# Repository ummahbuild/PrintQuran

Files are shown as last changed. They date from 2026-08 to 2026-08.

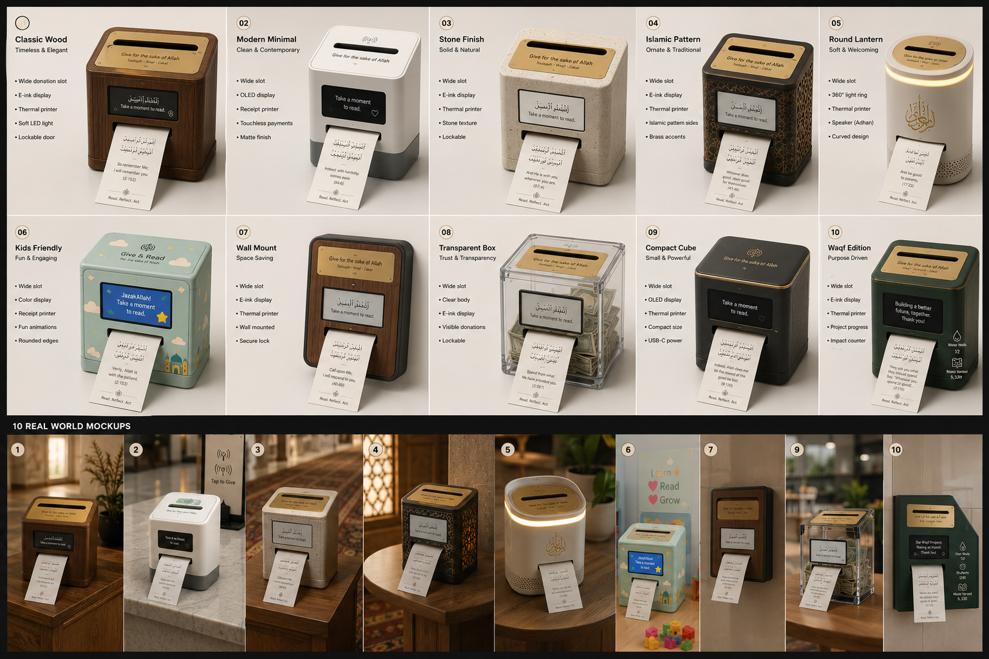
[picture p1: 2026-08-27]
reference-mockups/a_clean_product_design_board_concept_sheet_moc.png

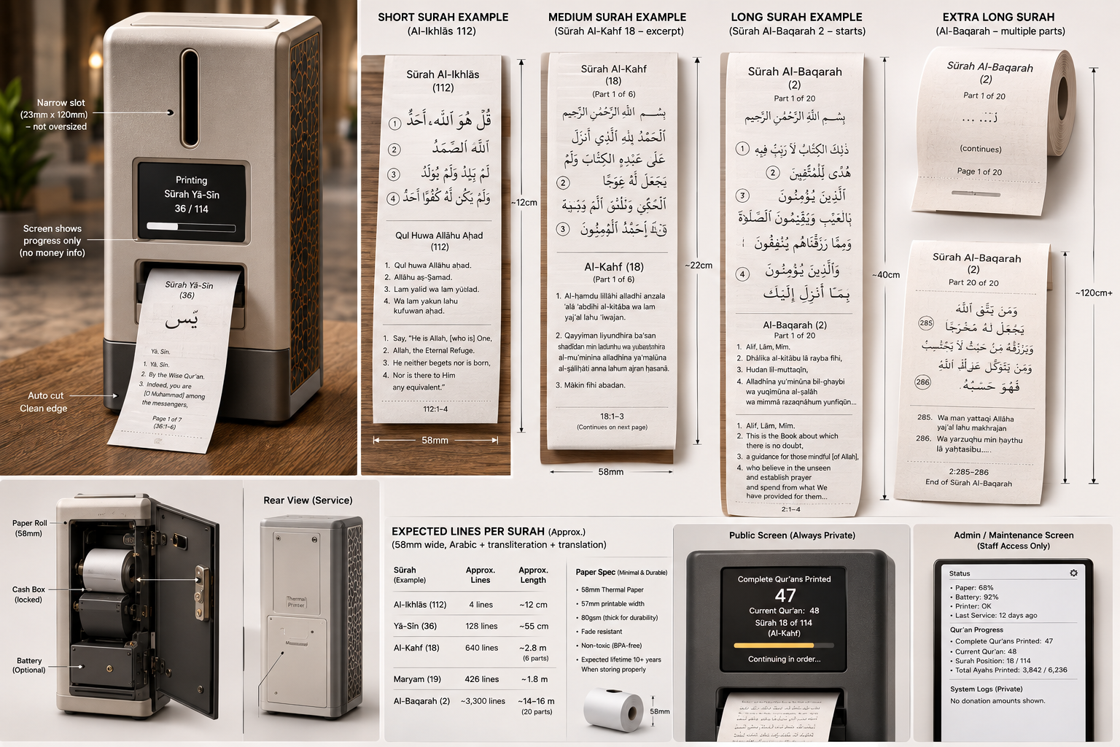
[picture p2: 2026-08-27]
reference-mockups/a_clean_high_resolution_product_design_ux_mockup.png

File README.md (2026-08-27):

# PrintQuran / Sadaqah to Qur’an — Production Hardware Repository v0.2

A production-readiness reference package for a secure mosque donation appliance that advances through the Qur’an in sūrah order and prints the selected sūrah after a donation event.

**Core product rule:** donation amount does not change the amount of Qur’an printed. One accepted donation event advances exactly one sūrah. Public UI never exposes donor count, donation amounts, or transaction history.

## Status
This repository is **pre-EVT engineering source**, not a certified production design. It contains detailed product requirements, supply-chain targets, mechanical reference CAD, electrical interfaces, firmware behavior, Qur’an content integrity rules, manufacturing tests, service procedures, compliance planning, packaging, and RFQ materials. Any drawing or part marked `REFERENCE` must be verified by qualified engineers before tooling or certification.

## v0.2 production direction
- 80 mm phenol-free thermal paper; 72 mm-class printable width preferred.
- 203 dpi embedded printer with cutter and paper-out sensor.
- ESP32-S3 controller; no Raspberry Pi required for the base model.
- 12 V external certified PSU, sized for printer peak current.
- Optional LiFePO4 backup module.
- Physically isolated cash vault and printer/service bay.
- Regional certified NFC/card terminal; core device never handles raw card credentials.
- Offline-first Qur’an bundle with signed manifests and immutable Arabic source.
- One global chassis; replaceable cosmetic shells and regional payment bezel.

## Start here
1. `docs/00-PRODUCTION-ROADMAP.md`
2. `docs/01-PRD.md`
3. `hardware/mechanical/MECHANICAL-SPEC.md`
4. `hardware/electrical/ELECTRICAL-SPEC.md`
5. `sourcing/BOM-master.csv`
6. `manufacturing/CM-RFQ.md`
7. `quality/DVT-TEST-MATRIX.csv`
8. `content/QURAN-INTEGRITY.md`
9. `service/FIELD-SERVICE-MANUAL.md`

The reference OpenSCAD model under `hardware/mechanical/cad/` is editable and can be exported to STL for fit studies. It is **not** a tooling-ready enclosure.

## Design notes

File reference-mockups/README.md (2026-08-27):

# Reference Mockups
These generated images are concept references only. They are NOT authoritative Qur'an sources, dimensional CAD, released factory drawings, certification evidence or final marketing claims. Any Qur'anic Arabic/translation/transliteration visible inside concept imagery must be replaced by the verified production rendering pipeline before publication or manufacture.

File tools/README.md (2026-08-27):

# Tools
`cost_summary.py` summarizes BOM target ranges.
`verify_bundle.py` demonstrates manifest-file hashing only; production signing/verification must use audited crypto libraries and secure key management.

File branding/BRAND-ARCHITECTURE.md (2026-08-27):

# Brand Architecture
The hardware platform should support white-label exterior panels and screen themes without changing core firmware integrity.

Candidate public brands:
- **Print Qur’an** — clearest functional/infrastructure name.
- **Sadaqah to Qur’an** — emotionally direct for voluntary giving deployments.
- **Sadaqah2Quran** — digital/startup variant.
- **Project 114** — campaign/institutional identity.

Avoid `Zakat2Quran` as the default unless a deployment has specifically established the relevant zakāt eligibility and governance; zakāt is not interchangeable with generic ṣadaqah.

Core palette options:
- Midnight Black + gold accents.
- Deep Brown + gold accents.
- Islamic Blue + gold accents.

Use one structural chassis. Color comes from powder coat/cosmetic side panels and printed UI theme.

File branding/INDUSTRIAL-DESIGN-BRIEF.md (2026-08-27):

# Industrial Design Brief
Form: low and wide, stable, dignified; avoid tall vending-machine proportions. Target 340 × 300 × 390 mm reference envelope.

Visual hierarchy:
1. narrow gold cash slot/bezel.
2. optional gold amount dial and NFC reader directly adjacent.
3. privacy-safe progress display.
4. paper exit.
5. subtle Qur’anic geometric pattern on side panels.

Do not print decorative pseudo-Arabic. Any Arabic shown in production UI must come from reviewed copy/content assets.

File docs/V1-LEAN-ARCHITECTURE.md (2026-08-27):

# PQ-CASH V1 Lean Architecture
Base V1 includes only: 80 mm cutter printer, ESP32-S3-class controller, 2.4-3.5 inch non-touch status display, narrow note slot, baffled steel chute, two optical donation-event sensors, isolated locked steel cash cassette, door/cassette sensing, external certified 12 V PSU, internal storage and service USB.

Removed: speaker, microphone, camera, touchscreen, bill-value recognition, amount dial, required Wi-Fi/battery, decorative audio/lighting and AI-generated Qur'anic content.

Cash path: slot -> baffle -> sensor A -> direction change -> sensor B -> cassette. Valid A-to-B motion creates one durable print credit. Print credit locks the next surah, preflights, renders, prints/cuts every part, commits, then advances.

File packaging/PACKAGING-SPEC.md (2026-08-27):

# Packaging Specification
Goals: survive parcel freight, protect printer/cutter and display, minimize plastic, prevent cosmetic abrasion.

Packout:
- device in nonwoven/PE sleeve as qualified.
- molded pulp or EPE corner/end caps.
- accessory box: PSU, keys in tamper-evident envelope, anchor kit, quick-start, starter paper roll if supplied.
- cash cassette secured for transport.
- printer transport restraint if supplier requires.

DVT packaging tests: drop sequence, vibration, compression/stacking, temperature/humidity conditioning as appropriate to distribution route.

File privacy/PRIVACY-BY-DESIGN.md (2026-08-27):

# Privacy by Design
Public output is based on Qur’an progression, not donor activity.

Public-safe examples:
- 47 complete Qur’ans printed.
- current Qur’an #48.
- current sūrah 18/114.
- āyāt printed in current Qur’an according to dataset.

Not public:
- donation amount.
- number of donations/donors.
- latest donation time.
- card/cash mix.
- payer identifiers.

Cash detector should generate only a donation event. Payment provider accounting remains separated from public progress UX.

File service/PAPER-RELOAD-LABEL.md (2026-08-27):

# Inside-door label copy
1. UNLOCK SERVICE LID
2. LIFT PRINTER COVER
3. DROP IN 80 mm ROLL — COATED SIDE AS MARKED
4. PULL 10 cm OF PAPER FORWARD
5. CLOSE PRINTER UNTIL IT CLICKS
6. CLOSE + LOCK SERVICE LID
7. DEVICE FEEDS/CUTS TEST PAPER AUTOMATICALLY

If RED status remains: scan service QR or report the error code. Never open the cash door to replace paper.

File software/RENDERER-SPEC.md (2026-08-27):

# Deterministic Print Renderer

Input: signed content bundle + signed/authorized print profile.
Output: ordered raster pages/strips plus a pagination manifest.

Rules:
- never split inside an āyah block unless a future reviewed mode explicitly supports it.
- calculate physical length from rendered raster rows, not estimated verse count.
- include sūrah number/name and part x/y on every part.
- verse number visually associated with its Arabic block.
- translation and transliteration labels/styles must make it impossible to confuse them with Qur’anic Arabic.
- maximum strip length configurable to reduce floor contact/curl.
- run preflight against remaining paper estimate before starting long jobs where sensor data supports it.

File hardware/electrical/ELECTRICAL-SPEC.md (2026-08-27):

# Electrical Specification

## Architecture
External certified 12 V supply → input protection → printer 12 V rail + DC/DC 5 V + 3.3 V rails.

Base controller: ESP32-S3 module. Keep Wi-Fi optional at runtime; printing and cash operation must work with radio disabled.

## Power budget
Design 12 V input for **5 A peak** unless selected printer data supports lower. Printer is the dominant transient load. Logic/display average should remain low enough that idle power is single-digit watts.

Minimum protections:
- replaceable or resettable input fuse.
- reverse-polarity protection.
- TVS/transient suppression.
- brownout detection.
- independent watchdog.
- current/voltage telemetry optional but recommended.

## Interfaces
- Printer: UART preferred for MCU simplicity; USB serial acceptable.
- Display: SPI/RGB depending module.
- Rotary encoder: GPIO with debounce.
- Cash sensors: isolated/filtered GPIO.
- Door switches: GPIO with tamper state.
- Payment terminal: isolated serial/USB/Ethernet/event API depending regional module. Only consume sanitized payment result + amount-selection state.
- Service USB-C: firmware/service only; do not expose unsecured debug shell in production.

## Battery
Optional LiFePO4 pack gets separate BMS and charging/power-path design. Battery is backup, not required for core SKU. Firmware may queue printing if battery voltage cannot support cutter/print peak.

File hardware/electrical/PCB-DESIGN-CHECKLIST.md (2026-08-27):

# PCB Design Checklist
- ESP32 antenna keepout respected.
- 4-layer stack recommended for EMC and robust ground.
- printer motor/current return kept away from RF/logic reference.
- TVS at external connectors.
- ESD strategy for USB and user-touch metal.
- locking production connectors.
- test pads for all rails, UART, boot, reset, door/cash sensors.
- serial number / MAC traceability.
- factory fixture pogo-pad area.
- no bootloader/debug access exposed without authorization.
- design reviewed against selected printer peak-current waveform.

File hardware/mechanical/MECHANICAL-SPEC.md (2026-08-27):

# Mechanical Specification

## Target envelope
Reference v0.2 envelope: **340 W × 300 D × 390 H mm**. Design goal is a low, wide countertop/floor-stand appliance rather than the taller concepts.

## Internal zoning
Top/front service bay:
- paper roll and printer.
- controller PCB/display.
- low-voltage power distribution.

Lower/rear secure zone:
- removable cash cassette.
- donation chute termination.

No service access panel may expose cash.

## Donation slot
Target clear opening: **135–155 mm wide × 8–11 mm high**, enough for folded notes without looking like a large open mouth. Gold bezel approximately 170–190 mm wide. Chute must include at least two direction changes or equivalent anti-fishing baffles.

## Paper
Design for 80 mm width and up to **83 mm OD** in base chassis if packaging permits. A 73–76 mm OD roll is preferred for common 70 m / heavyweight options.

## Serviceability
- paper roll replacement without tools after unlocking service lid.
- printer module replaceable with one screwdriver in <=10 minutes.
- PCB and display replaceable without drilling/rivets.
- harness connectors keyed and labeled.
- cash cassette removable independently.

## Mounting
Four hidden M6-equivalent anchor points in base. Provide optional wall/furniture tether kit.

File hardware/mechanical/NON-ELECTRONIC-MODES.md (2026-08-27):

# Non-Electronic Donation Modes
Cash Notes: narrow note slot, baffled chute, dual optical sensors, locked cassette. Detect event only, never value.

Manual Staff: momentary industrial button, spring-return key switch or foot pedal after staff accepts donation separately. Lowest mechanical complexity.

Envelope: separate top plate with roughly 170-190 mm wide x 12-18 mm high opening, anti-return geometry, deeper chute and dedicated cassette.

Coins: optional dedicated chute. Basic version detects passage only; currency-validating acceptors are regional and higher maintenance.

External Relay: opto-isolated dry-contact input from an existing donation system. One valid pulse creates one print credit.

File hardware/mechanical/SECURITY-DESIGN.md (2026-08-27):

# Physical Security Design

Threats: casual fishing, prying, opportunistic carry-away theft, unauthorized service-door opening, cash-door attack, insertion of foreign objects, and tamper attempts.

Controls:
- steel structural chassis.
- narrow slot with rounded bezel and anti-fishing chute.
- cash vault physically isolated.
- concealed hinge pins.
- recessed lock geometry.
- tamper switches on cash and service doors.
- internal anchor bolts.
- alarm event logging.
- no public external fasteners giving direct vault access.

Do not market as a safe or burglary-rated product unless independently tested/certified. DVT should include pry, fishing, tip, drop, and anchor tests with an agreed threat model.

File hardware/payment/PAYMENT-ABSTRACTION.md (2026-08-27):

# Regional Payment Abstraction

The core machine is not a payment terminal.

## UX
Rotary encoder selects preset donation amount for NFC/card. Presets are configured per deployment and currency. Cash donation ignores the dial.

## Interface contract
Payment module returns only:
- `PAYMENT_STARTED`
- `PAYMENT_APPROVED(transaction_token)`
- `PAYMENT_DECLINED(reason_class)`
- `PAYMENT_CANCELLED`
- `PAYMENT_OFFLINE`

Core firmware should not receive PAN/card credentials. Transaction token may be retained only when needed for reconciliation and under deployment policy.

## SKU strategy
Use an interchangeable payment bezel/adapter plate. Keep core chassis, controller, printer and software identical across countries.

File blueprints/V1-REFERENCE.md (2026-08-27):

# V1 Reference Blueprint
Front: narrow donation slot at top, small status screen below, 80 mm paper outlet below screen; no public controls on PQ-CASH.

Side: slot -> >=70 mm drop -> baffle -> sensor A -> second direction change -> sensor B -> cash cassette. Printer/roll/controller remain behind a full steel service/cash divider.

Electrical: certified 12 V PSU -> protected 12 V printer rail + efficient buck rails -> display/controller -> sensors/printer/display/service USB.

Printer bay starting clearance: 150 W x 125 H x 120 D, replaced by selected supplier STEP. Roll bay >=83 mm OD x 80 mm. Paper outlet ~92 W x 14 H, downward 10-20 degrees. Service opening target >=230 W x 160 H.

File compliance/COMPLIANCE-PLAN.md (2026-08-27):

# Compliance Plan — Engineering Planning Only

Exact obligations depend on sale country and payment module.

Likely workstreams:
- electrical/product safety for AV/ICT equipment and external PSU evidence (IEC/UL 62368-1 family commonly relevant).
- EMC emissions/immunity.
- radio approvals for Wi-Fi/BLE module/device by market.
- RoHS/REACH/material declarations where applicable.
- battery transport/safety documentation for optional LiFePO4 SKU.
- WEEE/e-waste and packaging obligations where applicable.
- payment terminal PCI/EMV/provider certifications handled by selected certified payment system, not recreated in the core device.
- accessibility/local language labeling requirements as applicable.

Before certification, commission a qualified compliance lab to write the formal test plan for target markets. Do not rely on this repository as legal/compliance advice.

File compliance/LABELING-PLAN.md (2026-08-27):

# Labeling Plan
Internal product label should reserve fields for model, serial, input rating, manufacturer/importer, country of origin, regulatory marks only after authorization, disposal symbols as applicable, and support URL/QR.

Public front should not include financial counters. Brand plate and Qur’an output are separate design layers so manufacturers can white-label the chassis without altering content integrity.

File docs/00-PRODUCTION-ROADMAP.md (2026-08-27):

# Production Roadmap

## Phase 0 — Requirements freeze
Exit only when the team freezes: 80 mm paper, max roll diameter, device envelope, printer interface, cash capacity, payment integration boundary, print profile schema, public privacy rules, target markets, and target cost.

## EVT (10–30 units)
Objectives: validate printer integration, power transients, paper path, long-sūrah pagination, cash chute anti-fishing geometry, serviceability, thermals, battery behavior, content integrity, and enclosure fit.

Mandatory EVT builds:
- 5 bench electronics rigs.
- 5 sheet-metal mechanical prototypes.
- 10 integrated devices minimum.
- at least 3 printer suppliers evaluated before design lock.

Exit gates:
- 10,000 automated print/cut cycles without state corruption.
- 500 donation-to-print cycles with no false sūrah advancement.
- power-cut recovery at every state transition.
- 100% content bundle signature rejection test coverage.
- paper reload <60 seconds by a first-time volunteer after reading the inside label.
- cash cassette removed/replaced without service bay access.

## DVT (30–80 units)
Objectives: validate near-production materials and fabrication, tamper resistance, ESD/EMI pre-compliance, temperature/humidity envelope, transport packaging, field maintenance, regional payment modules, and localization.

Exit gates include all rows marked `DVT_BLOCKER` in `quality/DVT-TEST-MATRIX.csv`.

## PVT (100–300 units)
Use the intended contract manufacturer, tooling, PCB assembler, harness vendor, locks, printer supplier, PSU, paper, carton, work instructions, end-of-line test fixture, and serialization flow.

Targets:
- first-pass yield >=95%.
- rework <3%.
- EOL test <6 minutes/device.
- assembly labor <20 minutes/device excluding burn-in.
- carton packout <4 minutes.

## Pilot deployment
20–50 devices across different mosque operating environments for 60–90 days. Record only operational telemetry and approved privacy-safe metrics; never expose donation amounts publicly.

## Production release
No release until compliance, safety, content review, manufacturing PPAP-like evidence, supplier change-control, warranty spares, and incident procedures are signed off.

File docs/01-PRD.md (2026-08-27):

# Product Requirements Document

## Product promise
A donor gives privately. The machine prints the next sūrah in Qur’anic order. The public sees Qur’an progress, not financial activity.

## Public UX
Idle screen may show:
- complete Qur’ans printed.
- current Qur’an sequence number.
- current sūrah / 114.
- current āyah-progress based on the configured canonical dataset.
- operational state.

Must not show publicly:
- donation totals or currency.
- number of donors/donations.
- timestamps or recent-donation feed.
- payment method history.

## Donation behavior
Cash: sensor detects an insertion event; denomination is intentionally not estimated. Card/NFC: certified payment terminal returns payment-success event. Any donation amount maps to one print job.

## Print profiles
Admin-selectable, versioned:
- Arabic script profile.
- Arabic renderer/font.
- translation language and specific translation edition.
- transliteration source/style.
- Arabic/transliteration/translation enable flags.
- font sizes and spacing within bounded tested ranges.
- paper-saving mode.
- QR footer enable/disable.
- max continuous strip length.
- language selection exposed to donor or locked by admin.

## Long sūrahs
One sūrah may produce multiple cuts. Each part must contain complete āyāt only, carry `Part x of y`, and the sūrah advances only after the final successful cut is committed.

## Availability
Core cash + print function must work offline indefinitely. Network is optional for fleet management, content updates, diagnostics, and payment-terminal connectivity where required.

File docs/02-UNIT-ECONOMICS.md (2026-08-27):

# Unit Economics Targets

These are engineering targets, not supplier quotes.

## Target landed hardware cost, excluding payment terminal
- EVT 10 units: $250–$450 each due to prototype fabrication and retail modules.
- 100 units: $135–$210.
- 500 units: $110–$170.
- 1,000 units: $95–$145.
- 5,000 units: $80–$125.

## Cost-down priorities
1. Printer module negotiated direct/OEM.
2. Folded steel enclosure DFM and common chassis across colors.
3. Custom controller PCB after EVT rather than dev boards.
4. Standard external PSU rather than internal mains supply.
5. One display size and one harness architecture.
6. Cosmetic shell/pattern panels separated from structural chassis.
7. Regional payment reader treated as add-on.
8. Phenol-free paper sourced locally by region when qualified.

## Retail architecture
Base cash model and connected payment model should be separate SKUs. Do not force every customer to subsidize payment certification, cellular service, or an oversized battery.

## Consumables
Paper is the main recurring consumable. Do not make paper proprietary; qualify dimensions and chemistry, then publish an approved-vendor list.

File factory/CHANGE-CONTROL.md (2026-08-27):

# Engineering Change Control
Any change to printer, paper chemistry/grammage, Arabic font/renderer, content source, PSU, battery, RF module, cash chute, lock, or controller PCB is a controlled change.

Change request must include reason, affected SKUs, compatibility, compliance impact, content integrity impact, test delta, old/new effective serial range, and rollback plan.

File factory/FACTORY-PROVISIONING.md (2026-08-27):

# Factory Provisioning
Factory firmware is not production firmware.

Provisioning station:
1. reads PCB serial/MAC.
2. runs board test.
3. writes device certificate/identity if fleet mode used.
4. flashes signed production firmware.
5. installs signed content bundle selected for SKU/region.
6. writes immutable manufacturing record: BOM rev, PCB rev, printer lot, display lot, PSU lot, enclosure lot.
7. runs EOL.
8. locks debug features according to release policy.

Signing keys must never be present on the contract-manufacturer line in exportable form.

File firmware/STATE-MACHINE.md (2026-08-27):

# Print State Machine

`IDLE -> DONATION_PENDING -> DONATION_ACCEPTED -> JOB_LOCKED -> PREFLIGHT -> RENDER -> PRINT_PART -> VERIFY_CUT -> ... -> COMMIT_SURAH -> THANK_YOU -> IDLE`

## Atomicity rule
The current sūrah pointer advances only after the final part has returned a successful print/cut completion and the durable job journal is committed.

## Recovery
Every transition writes an append-only journal record with job UUID, content bundle hash, print profile hash, sūrah, part, and status. On reboot, incomplete jobs resume or enter service-recovery; they never silently advance.

## Cash debounce
A cash event requires a valid beam sequence lasting within configured min/max duration. Lockout prevents multiple prints from one note moving through the chute. Coins require a dedicated separate sensor path if supported; v1 may be notes-only to reduce false events.

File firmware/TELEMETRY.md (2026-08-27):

# Telemetry Policy
Allowed operational telemetry when enabled:
- device online/offline.
- printer error class.
- paper-low estimate.
- cutter/head usage.
- firmware/content versions.
- battery health.
- service/cash door tamper event.

Do not publish donation amounts, donor count, donation timestamps, or payment history to the public display. Fleet backend financial telemetry is out of the core device scope and must follow deployment privacy/accounting rules.

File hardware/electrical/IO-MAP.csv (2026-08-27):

Signal | Direction | Voltage | Connector | Notes
PRINTER_TX | OUT | 3.3V UART | J3 | level shift if printer requires RS232/5V
PRINTER_RX | IN | 3.3V UART | J3
PRINTER_PWR_EN | OUT | 3.3V | J3 | drives MOSFET/load switch
CASH_BEAM_A | IN | 3.3V | J4 | filtered
CASH_BEAM_B | IN | 3.3V | J4 | optional direction confirmation
SERVICE_DOOR | IN | 3.3V | J5 | normally-closed preferred
CASH_DOOR | IN | 3.3V | J5 | normally-closed preferred
ENC_A | IN | 3.3V | J6 | rotary encoder
ENC_B | IN | 3.3V | J6
ENC_PUSH | IN | 3.3V | J6
DISPLAY | BI | 3.3V | J7 | SPI/RGB by selected module
PAYMENT_EVENT | BI | isolated | J8 | regional module abstraction
BATTERY_SENSE | IN | ADC | J9 | optional SKU
BUZZER | OUT | 3.3V | J10 | service alerts

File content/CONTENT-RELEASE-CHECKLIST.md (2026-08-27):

# Content Release Checklist
- source license verified.
- exact source version pinned.
- Arabic file hash recorded.
- translation resource + edition named on admin screen and release manifest.
- transliteration resource named.
- font license cleared for embedding/distribution.
- representative printed proofs reviewed by qualified Qur’an/content reviewers.
- automated verse/sūrah sequence test passes.
- no missing/duplicate āyah IDs.
- golden raster suite passes.
- manifest signed with release key held outside source repository.

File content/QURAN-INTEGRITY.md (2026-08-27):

# Qur’an Content Integrity

## Non-negotiable architecture
AI must not generate, paraphrase, autocorrect, or dynamically translate Qur’anic Arabic at print time.

Pipeline:
1. import an approved canonical Arabic dataset under its license.
2. preserve source text exactly.
3. import specifically identified translation/transliteration resources.
4. normalize only metadata in a documented process; never silently mutate Arabic.
5. generate per-āyah SHA-256 hashes.
6. human review bundle/version metadata.
7. sign release manifest.
8. device verifies manifest and assets before rendering.

## Rendering
Arabic text is shaped by a tested renderer/font profile. Arabic source data and glyph rendering are separate layers. Every print test fixture should include golden raster comparisons for representative āyāt covering diacritics, ligatures, punctuation, and long lines.

## Progress metric
Do not hard-code a universal āyah total. The public progress denominator comes from the exact selected canonical bundle/numbering convention.

## Licensing
Tanzil and Quran Foundation/Quran.com resources have distinct usage/licensing expectations. Translation licenses vary by resource. Release engineering must keep a machine-readable provenance record and block any bundle without cleared redistribution rights.

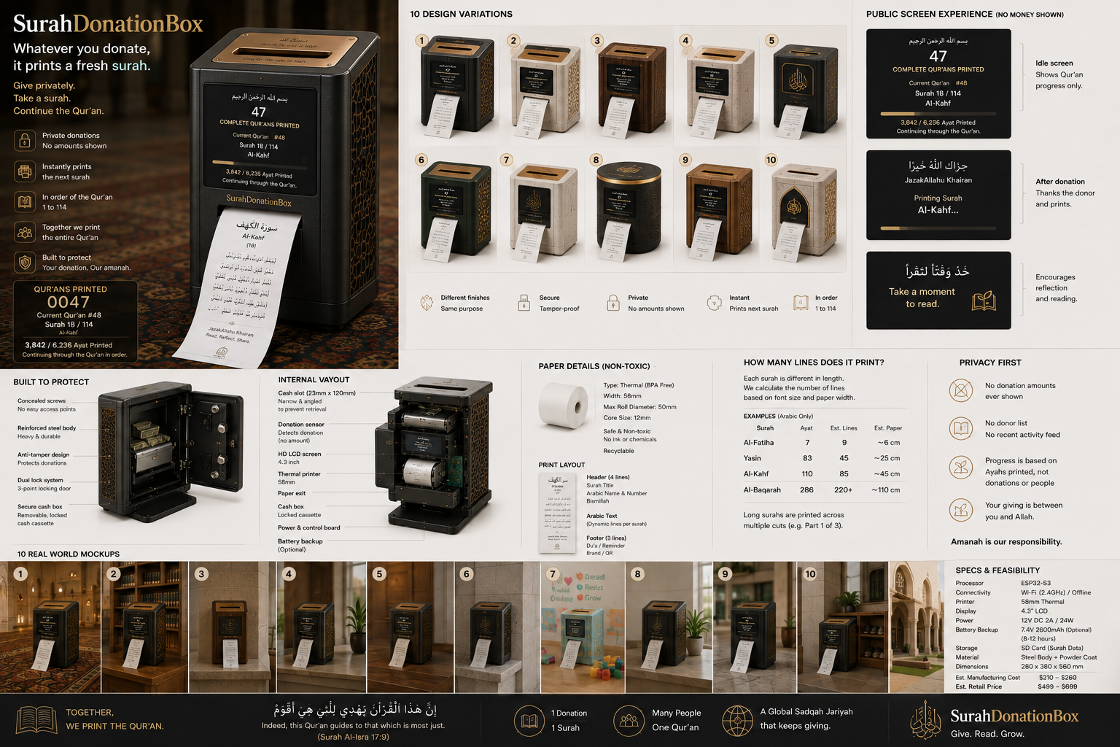
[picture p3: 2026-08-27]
reference-mockups/a_high_detail_multi_panel_product_concept_market.png

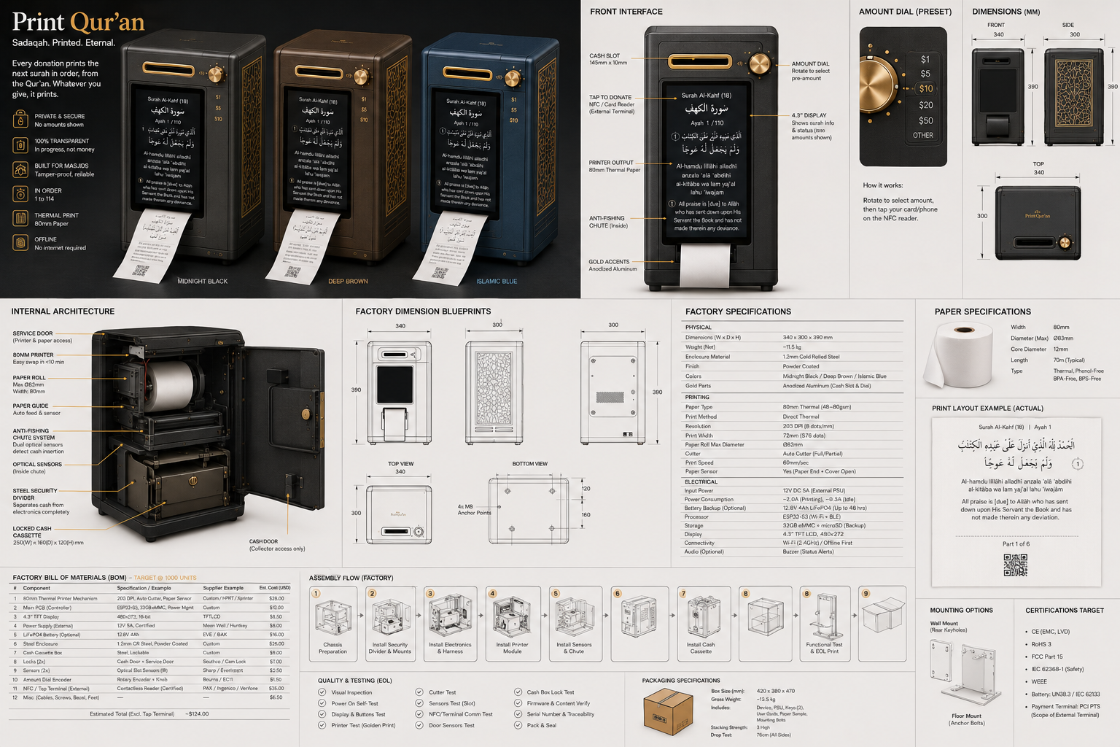
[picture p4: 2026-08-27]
reference-mockups/a_detailed_technical_product_infographic_design.png

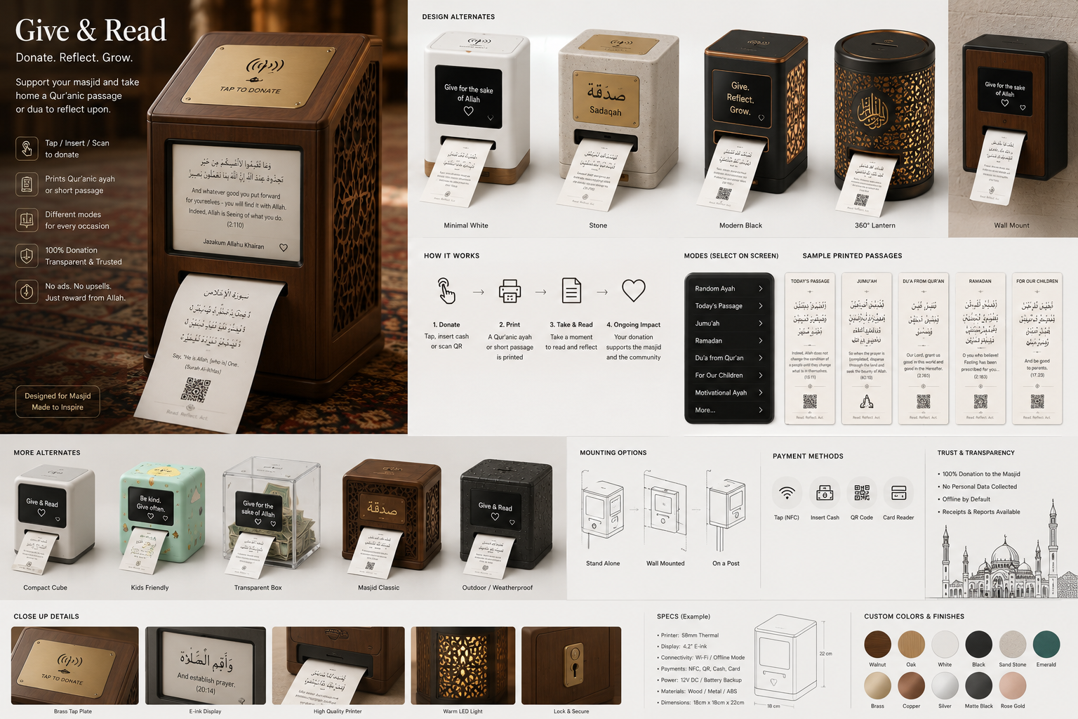
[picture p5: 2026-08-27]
reference-mockups/a_clean_product_design_concept_board_infographic.png

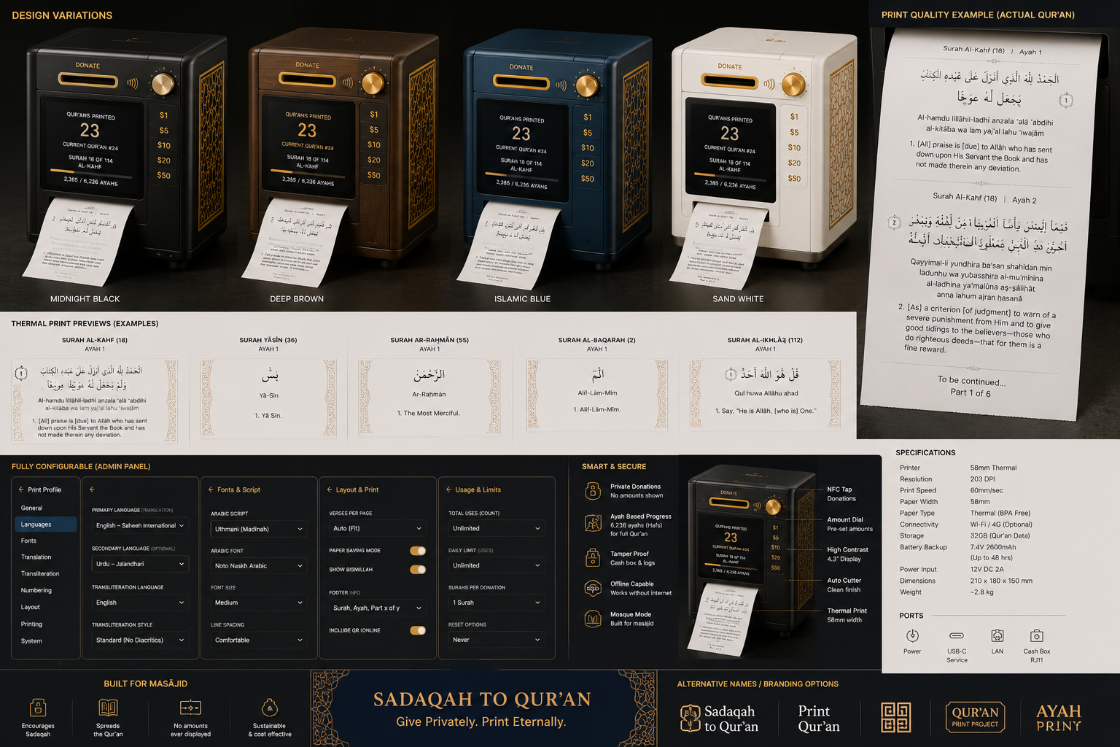
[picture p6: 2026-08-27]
reference-mockups/a_high_resolution_product_design_presentation_mood.png

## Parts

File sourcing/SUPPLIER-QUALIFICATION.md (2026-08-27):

# Supplier Qualification

## Critical components
Printer, PSU, paper, cash lock, battery/BMS, PCB assembly, steel chassis, and payment terminal are critical.

## Printer supplier scorecard
Require:
- exact printable width and dpi.
- 12 V power/current waveform, not just nominal current.
- head rated distance and cutter rated cycles.
- paper thickness/grammage range.
- cutter jam recovery behavior.
- status/error interface documentation.
- UART/USB/RS-232 protocol documentation.
- Linux/MCU driver availability or ESC/POS command support.
- sample lead time, MOQ, production lead time, warranty.
- PCN/EOL notice policy.
- factory quality certification.

Buy 3–5 samples from at least three candidates and run the same 10k-cycle fixture test.

## Paper qualification
Approve by paper grade, not only reseller SKU. Record width, OD, core, gsm, coating side, phenol-free declaration, image-life claim, curl after printing, dust, cutter behavior, black density, storage conditions, and supplier lot traceability.

Current public examples show 80 mm phenol-free/BPA-free/BPS-free supply in multiple lengths and grammages; the project should still perform independent incoming verification and supplier document review.

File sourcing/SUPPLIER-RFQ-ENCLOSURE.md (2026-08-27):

# RFQ — Sheet Metal Enclosure

Material target: cold-rolled steel, 1.2 mm structural shell; 1.5 mm cash vault where required. Powder coat exterior, zinc/passivation or equivalent corrosion control on hidden surfaces where appropriate.

Quote prototype laser-cut/bent and production tooling options at 10/100/500/1k/5k. Include welding, PEM hardware, powder coat, inspection, packaging, and dimensional capability.

Critical features:
- cash/service compartment separation.
- concealed or internal hinges.
- anchor points.
- replaceable cosmetic side panels.
- printer alignment datum.
- no sharp internal service edges.

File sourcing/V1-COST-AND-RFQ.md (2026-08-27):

# V1 Cost Targets and RFQ
Engineering targets at about 1,000 units: printer $28-45; controller PCBA $10-16; small display $4-8; steel chassis $18-28; cash cassette/chute $10-18; locks $5-9; sensors/doors $2-4; certified PSU $7-11; harness/fasteners $5-8; bezel/cosmetics $4-7; assembly/EOL $7-12; packaging $5-8. Indicative target roughly $100-174 before freight, duty, certification, warranty reserve, margin or optional payment terminal. These are targets, not supplier quotes.

RFQs must quote 10/100/500/1000/5000 units and separate metalwork, coating, PCBA, harness, printer, display, locks/cassette, PSU, assembly, EOL, packaging, NRE/tooling and certification support. Return MOQ, lead time, origin, alternates, PCN/EOL policy, warranty, capacity and DFM recommendations.

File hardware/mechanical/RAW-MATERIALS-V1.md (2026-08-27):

# Raw Materials V1
Main shell: 1.2 mm cold-rolled low-carbon steel. Security divider: 1.5 mm steel. Cash door/anchor: 1.5-2.0 mm steel. Chute: 1.0-1.2 mm coated/galvanized steel. Cassette: 1.2-1.5 mm steel. Gold bezel: 2-3 mm aluminum, CNC/stamped/die-cast by volume, anodized/decorative durable finish. Display window: 1.5-2 mm hard-coated polycarbonate. Internal molded brackets: PC-ABS ~2-2.5 mm nominal after DFM. Gaskets: EPDM/silicone foam. PCB: 4-layer FR-4. Harness: stranded copper sized by measured load. Packaging: double-wall corrugated plus qualified protective inserts.

Reference envelope 340 W x 300 D x 390 H mm. Cash opening 145 W x 10 H; bezel about 185 W x 42 H. First chute drop >=70 mm and at least two direction changes. Cassette useful target 250 W x 160 D x 120 H. Four internal M8 anchors. These are starting points, not tooling-release dimensions.

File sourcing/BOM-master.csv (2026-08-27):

Category | Ref | Part / Requirement | Preferred spec | Qty | 100u target USD | 1000u target USD | Alternates / Notes
Compute | U1 | ESP32-S3 module | 8MB flash; PSRAM optional | 1 | 4.5-6.5 | 3.5-5.0 | Use module for RF certification leverage
PCB | PCB1 | Main controller PCB | 4-layer preferred, 1.6mm FR4 | 1 | 8-14 | 4-7 | Includes DC/DC and printer drivers/interfaces
Printer | PRN1 | 80mm embedded thermal printer | 203dpi, 72mm-class print width, cutter, paper sensor | 1 | 38-60 | 28-45 | Qualify 3 suppliers
Display | DS1 | 4.3in TFT | 480x272 or better, non-touch | 1 | 10-16 | 7-11 | E-ink optional premium variant
Power | PSU1 | External PSU | 12V 5A, regional plugs, certified | 1 | 10-16 | 7-11 | UL/IEC 62368-1 evidence as applicable
Power | BAT1 | LiFePO4 backup module | 12.8V 3-4Ah with BMS | 0.5 | 18-28 | 14-22 | Optional SKU
Mechanical | CH1 | Folded steel chassis | 1.2mm powder coated | 1 | 22-36 | 15-26 | Structural, common across finishes
Mechanical | CV1 | Cash vault/cassette | 1.5mm steel, removable | 1 | 10-18 | 7-12 | Separate from service compartment
Security | LK1 | Cash lock | tubular or high-quality cam lock | 1 | 5-9 | 3-6 | Keyed-alike/keyed-different options
Security | LK2 | Service lock | cam lock | 1 | 3-6 | 2-4 | Different key from cash lock
Mechanical | G1 | Gold cash slot bezel | die cast / machined prototype; plated production | 1 | 4-10 | 2-6 | Avoid solid brass cost
Mechanical | PNL | Decorative side panels | PC/ABS or aluminum overlay | 2 | 8-16 | 4-9 | Black/brown/blue printed or coated
Input | ENC1 | Rotary encoder + knob | detents + push | 1 | 2-4 | 1-2 | Amount selector for payment terminal only
Sensor | S1 | Cash beam sensor | dual optical beam preferred | 1 | 1-3 | 0.6-1.5 | Detect event, not denomination
Sensor | S2 | Paper out/near-end | printer-native + optional near-end | 1 | 1-2 | 0.5-1
Sensor | S3 | Service door switch | tamper microswitch | 1 | 0.5-1.5 | 0.25-0.7
Sensor | S4 | Cash door switch | tamper microswitch | 1 | 0.5-1.5 | 0.25-0.7
Audio | SPK1 | Small speaker/buzzer | service alerts only | 1 | 1-2 | 0.5-1 | Disableable
Storage | SD1 | Industrial microSD | 8-16GB | 1 | 5-9 | 3-6 | Optional if internal flash sufficient
Harness | WH1 | Main wiring harness | locking connectors | 1 | 5-9 | 3-6 | No loose Dupont headers in production
Hardware | HW | Fasteners, feet, anchors | security Torx where exposed | 1 | 5-8 | 3-5
Packaging | PKG | Carton + molded pulp/EPE | drop-testable | 1 | 8-14 | 5-9 | Prefer recyclable molded pulp

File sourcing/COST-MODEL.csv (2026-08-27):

Volume | Electronics | Printer | Mechanical+locks | Power | Harness+sensors | Packaging | Assembly+test | Target ex-factory total
10 | 70 | 85 | 140 | 35 | 25 | 18 | 55 | 428
100 | 42 | 50 | 70 | 24 | 16 | 12 | 25 | 239
500 | 31 | 40 | 50 | 20 | 12 | 9 | 18 | 180
1000 | 26 | 35 | 43 | 18 | 10 | 8 | 15 | 155
5000 | 21 | 30 | 34 | 16 | 8 | 7 | 12 | 128
NOTE |  |  |  |  |  |  |  | Targets only; obtain RFQs before business decisions

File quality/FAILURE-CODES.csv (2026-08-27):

Code | User message | Admin detail | Field action
P01 | Printer needs attention | Paper out | Reload paper
P02 | Printer needs attention | Cutter jam | Open service bay and clear per manual
P03 | Service required | Head overtemp | Allow cool-down; inspect ventilation
C01 | Service required | Cash sensor blocked | Inspect chute
D01 | Service required | Service door open | Close/lock service door
D02 | Service required | Cash door open | Close/lock cash door
B01 | Temporarily unavailable | Battery too low to print | Restore mains / charge
Q01 | Service required | Content signature invalid | Install authorized bundle
S01 | Resuming your sūrah | Interrupted job journal found | Automatic resume/service if jammed

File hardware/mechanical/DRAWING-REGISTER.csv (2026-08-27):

ID | Part | Status | Owner | Needed for
ME-001 | Structural chassis | REFERENCE | Mechanical | EVT
ME-002 | Top bezel | REFERENCE | Industrial Design | EVT
ME-003 | Cash cassette | TO DESIGN | Mechanical | EVT
ME-004 | Anti-fishing chute | TO DESIGN | Mechanical | EVT
ME-005 | Printer bracket | TO DESIGN | Mechanical | EVT
ME-006 | Display bracket | TO DESIGN | Mechanical | EVT
ME-007 | Side cosmetic panel | TO DESIGN | Industrial Design | DVT
ME-008 | Packaging inserts | TO DESIGN | Packaging | DVT

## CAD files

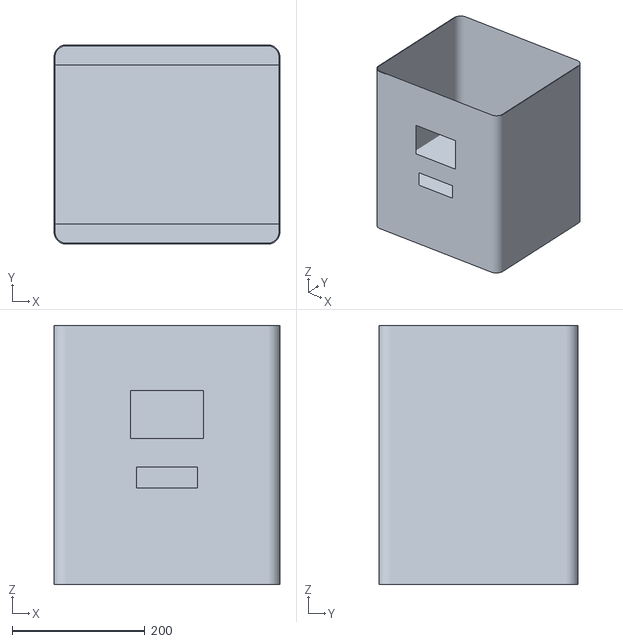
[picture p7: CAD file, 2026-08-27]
hardware/mechanical/cad/enclosure_reference.stl
340.0 x 300.0 x 390.0

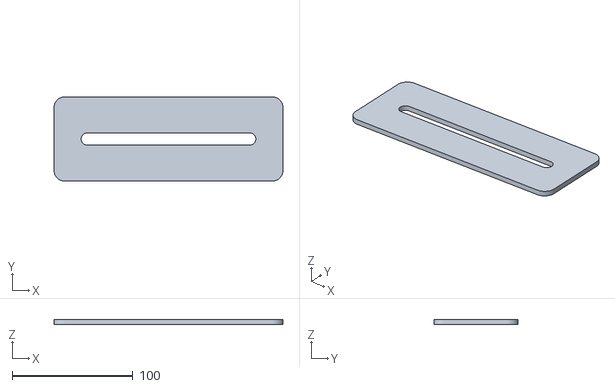
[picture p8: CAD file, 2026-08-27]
hardware/mechanical/cad/top_bezel_reference.stl
190.0 x 70.0 x 4.00

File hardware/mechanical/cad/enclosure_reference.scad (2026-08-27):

// PrintQuran v0.2 REFERENCE fit-study model — NOT tooling ready.
// Units: mm
$fn=48;
W=340; D=300; H=390; wall=1.5; corner=18;
slot_w=145; slot_h=10;
display_w=110; display_h=72;
printer_w=92; printer_h=32;

module rounded_box(w,d,h,r){
  hull(){ for(x=[r,w-r]) for(y=[r,d-r]) translate([x,y,0]) cylinder(h=h,r=r); }
}
module shell(){
 difference(){
  rounded_box(W,D,H,corner);
  translate([wall,wall,wall]) rounded_box(W-2*wall,D-2*wall,H-wall,corner-wall);
  // front display opening
  translate([(W-display_w)/2,-1,220]) cube([display_w,wall+3,display_h]);
  // printer exit
  translate([(W-printer_w)/2,-1,145]) cube([printer_w,wall+3,printer_h]);
  // top donation slot
  translate([(W-slot_w)/2,70,H-4]) cube([slot_w,slot_h,8]);
 }
}
module divider(){ translate([wall,30,120]) cube([W-2*wall,D-60,1.5]); }
module cash_vault(){
 translate([55,70,15]) difference(){ cube([230,190,95]); translate([2,2,2]) cube([226,186,95]); }
}
color("#171717") shell();
color("#777777") divider();
color("#444444") cash_vault();

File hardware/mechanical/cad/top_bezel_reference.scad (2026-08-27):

// REFERENCE top bezel for fit/visualization only.
$fn=48;
W=190; D=70; T=4; R=9; slot_w=145; slot_h=10;
module rr(w,d,h,r){ hull(){for(x=[r,w-r])for(y=[r,d-r])translate([x,y,0])cylinder(h=h,r=r);} }
difference(){ rr(W,D,T,R); translate([(W-slot_w)/2,(D-slot_h)/2,-1]) rr(slot_w,slot_h,T+2,slot_h/2); }

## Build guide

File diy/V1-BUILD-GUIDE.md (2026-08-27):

# DIY V1 Build Guide
1. Buy ESP32-S3 dev board, qualified 80 mm 203-dpi cutter printer, certified low-voltage PSU and phenol-free paper.
2. Measure actual printer dots per line and calibrate density/cutter.
3. Render reviewed Arabic to monochrome bitmap; add ayah marker and optional approved translation/transliteration.
4. Implement atomic print state and pull power during every state to prove resume.
5. Use a button as simulated donation trigger.
6. Add two optical sensors and a baffled prototype chute.
7. For real money, use a purchased lockable steel cash box; do not use printed plastic as a safe.
8. Keep service and cash physically separated, anchor enclosure, then commission privacy/content/print tests.

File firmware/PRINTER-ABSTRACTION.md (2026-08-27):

# Printer Hardware Abstraction
Required operations:
- `status()`
- `feed(mm)`
- `print_bitmap(rows)`
- `cut()`
- `paper_present()`
- `temperature_state()` if available
- `error_state()`

Rendering to a deterministic raster before print is preferred for Arabic shaping consistency across printer vendors. Printer-native text fonts must not be trusted for Qur’an rendering.

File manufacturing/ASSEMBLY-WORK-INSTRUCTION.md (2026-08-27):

# Assembly Work Instruction — Draft
1. Verify chassis lot and finish.
2. Install PEM hardware / anchors.
3. Install cash chute and cassette guides.
4. Perform chute go/no-go gauge inspection.
5. Install cash and service locks; verify distinct access.
6. Install printer bracket and printer.
7. Install display and front bezel.
8. Install controller PCB and harness.
9. Install sensors and confirm mechanical actuation.
10. Install PSU inlet/low-voltage connector assembly.
11. Optional battery module.
12. Flash factory firmware and device identity.
13. Run EOL automated fixture.
14. Load production firmware and signed content bundle.
15. Security fastener torque witness marking.
16. Cosmetic inspection and clean.
17. Pack approved paper starter roll separately unless shipping rules permit installed roll.
18. Final serial scan and carton seal.

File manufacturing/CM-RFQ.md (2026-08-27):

# Contract Manufacturer RFQ Package

Request quote for EVT 20, DVT 50, PVT 200, and production 1k/5k.

CM scope desired:
- sheet metal or enclosure subassembly.
- PCB assembly and programming.
- harness manufacture.
- printer/display/lock integration.
- full mechanical assembly.
- end-of-line test.
- serialization and label application.
- carton packout.
- outgoing inspection.

Require quote breakdown for materials, labor, NRE/tooling, test fixture, packaging, freight assumption, scrap, warranty reserve, MOQ, lead time, payment terms, and component alternates.

CM must not substitute printer, PSU, battery, locks, paper, RF module, or content-storage components without written engineering change approval.

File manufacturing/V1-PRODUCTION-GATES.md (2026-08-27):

# V1 Production Gates
EVT 10-20: >=3 printer candidates, >=3 paper stocks, approved Arabic golden output, >=10k print/cut cycles, power interruption every state, long-job thermal, false-trigger/security/paper reload/pre-scan.

DVT 30-80: production-intent construction, >=50k aggregate print/cut stress target, shipping/environmental/cleaner tests, pre-compliance, privacy review, service-time validation.

PVT 100-300: target FPY >=95%, rework <3%, EOL <=6 min, assembly <=20 min, packout <=4 min, full traceability, AVL and spares ready.

Factory EOL captures serial/hardware revision, PCBA/printer/PSU lots, firmware/content hashes and tests rails, display, cash A/B, doors/cassette, printer/paper, approved golden Qur'an strip, cutter, storage and service USB. Factory prints never advance the real sequence.

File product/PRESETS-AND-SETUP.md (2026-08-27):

# Presets and Setup
Configuration = country pack + institution preset + donation mode + approved print profile + detected hardware + privacy + maintenance.

Wizard: country -> donation mode -> public language -> approved print profile -> printer test -> trigger test -> privacy check -> anchor/commission.

Modes: Cash Only, Manual Staff, Envelope, Tap Only, Cash+Tap, Existing Donation System, Sponsored, Education, Demo. Cash Only hides payment menus, has no amount selector, needs no network and never estimates denomination.

Country packs may suggest currency formatting, timezone, UI languages, power lead and optional payment adapters, but must never silently choose religious content.

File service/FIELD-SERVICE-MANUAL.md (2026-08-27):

# Field Service Manual

## Volunteer tasks
- replace paper.
- wipe exterior.
- read status screen.
- report error code.

## Authorized service tasks
- clear cutter jam.
- replace printer module.
- replace PSU/controller/display/sensor.
- battery replacement.
- firmware/content update.

## Cash collection
Cash key and service key must be operationally separable. Collection procedure must not require opening printer/service electronics.

## Preventive maintenance
Monthly: visual paper path/cutter dust check, locks, anchor, door sensors.
Quarterly: print quality test, chute inspection, cooling vents, harness inspection where accessible.
Annually: printer usage review, battery health where fitted, security/anchor check, firmware/content status.

## Cleaning
Use only printer-manufacturer-approved print-head cleaning procedure/material. Never spray liquid into the device. Power down before internal service.

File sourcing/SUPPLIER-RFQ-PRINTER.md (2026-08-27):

# RFQ — Embedded 80 mm Thermal Printer

Quote at 10 / 100 / 500 / 1,000 / 5,000 units.

Required:
- 80 mm media.
- 203 dpi.
- >=72 mm preferred printable width.
- auto cutter.
- paper-out sensor.
- 12 V DC preferred.
- peak current data.
- UART and/or USB serial interface.
- status query for paper, cutter, head temperature, errors.
- drop-in roll loading.
- field-replaceable mechanism.
- paper 48–80 gsm support desired.
- head life >=100 km target.
- cutter >=1M cuts target.

Please include STEP model, mounting drawing, connector mating part numbers, protocol manual, reliability report, certifications, sample pricing, NRE, tooling, MOQ, warranty, and PCN policy.

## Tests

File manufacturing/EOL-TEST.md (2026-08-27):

# End-of-Line Test
Target <6 minutes/device.

Automated checks:
- serial/MAC identity.
- firmware signature/version.
- content manifest signature/version.
- all rails within limits.
- display pixels/test image.
- encoder and push switch.
- cash sensor beam sequence using fixture flag.
- service/cash door switches.
- printer status.
- print golden test strip with Arabic glyph test raster + QR/serial block.
- cutter operation.
- optional battery voltage/charge path.
- payment-module interface loopback where installed.
- Wi-Fi/BLE RF sanity test, not a substitute for certification.

Operator scans test strip and fixture records PASS/FAIL against serial.

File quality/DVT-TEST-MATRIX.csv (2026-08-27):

ID | Area | Test | Acceptance | Priority
DVT-001 | Print | 10000 print/cut cycles | No unrecovered state corruption; jam rate within printer target | DVT_BLOCKER
DVT-002 | State | Power cut during every state | No double advancement or lost job | DVT_BLOCKER
DVT-003 | Content | Corrupt bundle signature | Device refuses print and shows service error | DVT_BLOCKER
DVT-004 | Content | Golden raster Arabic suite | Pixel output matches approved baseline | DVT_BLOCKER
DVT-005 | Mechanical | Paper reload novice test | Median <60 sec and no cash access | DVT_BLOCKER
DVT-006 | Security | Fishing attempts through slot | No easy retrieval under agreed fixture/test | DVT_BLOCKER
DVT-007 | Security | Anchor pull/tip | Meets defined installation load | DVT_BLOCKER
DVT-008 | Environment | 0-40C operating trial | No unsafe condition; print performance within spec | HIGH
DVT-009 | Environment | 20-80%RH non-condensing | No corrosion/jam beyond limits | HIGH
DVT-010 | EMC | ESD pre-scan | No reset/data corruption at target levels | DVT_BLOCKER
DVT-011 | EMC | Conducted/radiated pre-scan | Engineering margin before formal test | DVT_BLOCKER
DVT-012 | Power | Printer peak transient | No brownout; rails within limits | DVT_BLOCKER
DVT-013 | Battery | Low battery print inhibit | Long print not started below threshold | HIGH
DVT-014 | Transport | Packaged drop test | No functional/cosmetic failure beyond criteria | HIGH
DVT-015 | Service | Printer swap | Trained tech <10 min | HIGH
DVT-016 | Privacy | Public UI review | No amounts/count/timestamps visible | DVT_BLOCKER
DVT-017 | Payment | Declined/cancel flow | No print on unsuccessful transaction | DVT_BLOCKER
DVT-018 | Cash | Single-note beam debounce | One event produces one job | DVT_BLOCKER
DVT-019 | Paper | 3 approved paper grades | No unacceptable curl/dust/cutter failure | HIGH

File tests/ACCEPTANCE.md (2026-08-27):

# Release Acceptance
No production release unless:
- all DVT_BLOCKER rows pass.
- production Qur’an content bundle receives documented review/signoff.
- printer and paper combination is qualified.
- formal compliance plan/test results exist for target sale markets.
- cash/service separation verified.
- payment module boundary validated.
- PVT yield target met.
- field-service spares available.
- manufacturing change control enabled.

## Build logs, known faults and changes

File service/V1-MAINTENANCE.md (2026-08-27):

# V1 Maintenance
Volunteer: inspect outlet, wipe exterior with approved cleaner, reload paper, report error code; no cash access.
Cash collector: separate key, swap/remove cassette; no electronics access.
Technician: replace printer/controller/display/sensor/PSU, update signed firmware/content and run diagnostics.
Targets: printer/controller/display/sensor <10 minutes; PSU <5 minutes; no field soldering.
Starting spares per 100 deployed: 5 printers, 5 PSUs, 3 controller boards, 3 displays, 5 lock sets, 10 sensor modules, 3 harnesses.
